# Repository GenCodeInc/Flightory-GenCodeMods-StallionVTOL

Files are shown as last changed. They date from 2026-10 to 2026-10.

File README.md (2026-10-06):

# FlightoryGenCodeMods — Stallion VTOL

Motor-mount modification and wingtip LED scripts for the Flightory Stallion VTOL. All files are in the repository root.

## Motor Mount

Modified front motor mount for the SPARKHOBBY / KINGMAX KM1203MD mini digital servo.

| File | Contents |
| --- | --- |
| `MOTOR MOUNT FRONT-LARGER-HORN-METAL.f3d` | Editable Fusion 360 design |
| `MOTOR MOUNT FRONT-LARGER-HORN-METAL.stl` | Printable mesh |

## Wingtip LED Scripts

Two SpeedyBee WS2812 boards, four LEDs per wing, controlled by a TBS Lucid H7 Wing running ArduPilot Lua through S13. No separate LED controller is used.

### stallion_led_nav.lua

- Left wing red; right wing green.
- All four LEDs on each wing show their navigation colour between flashes.
- Rear two LEDs per wing flash white twice; front two remain red/green.
- Full-brightness navigation colours and white strobes.
- Timing: 60 ms flash, 80 ms gap, 60 ms flash, 900 ms pause.
- Strobes run while disarmed by default.

### stallion_led_demo.lua

Four patterns run for five seconds each, then repeat:

1. **UFO orbit:** purple comet with a fading trail through all eight LEDs in data-chain order.
2. **Police pursuit:** alternating red/blue double flashes between wings.
3. **Rainbow chase:** moving rainbow colours across all eight LEDs.
4. **Reactor pulse:** cyan pulse with a white flash at the peak.

Brightness is controlled by `BRIGHTNESS` (0–255). The demo setting used for this build is `180`.

## LED Wiring

| Source | Destination |
| --- | --- |
| FC S13 | Left-wing DIN |
| Left-wing DOUT | Right-wing DIN, routed through the fuselage |
| Right-wing DOUT | Unconnected |
| Regulated 5 V | Both boards' positive inputs |
| Common ground | Both boards' negative inputs and FC ground |

DIN faces the front of each wing; DOUT faces the rear. The first four pixels are on the left wing, and the next four are on the right wing. The 5 V supply must support the LED load, including white flashes.

## Installation

1. Set `SCR_ENABLE = 1` and `SERVO13_FUNCTION = 94` (Script Out 1).
2. Copy either `stallion_led_nav.lua` or `stallion_led_demo.lua` into `APM/scripts` on the FC's SD card.
3. Remove any other script controlling these LEDs from that folder.
4. Reboot the FC.

Run only one LED script at a time. Filenames may be changed but must retain the `.lua` extension. The demo replaces the navigation-light pattern while installed.

## Credits

Original aircraft design: [Flightory](https://flightory.com/product/stallion/). Modifications: Ed Scott / GenCode. LED project inspired by Ralf Åhman's ESP32 navigation lights.

Original aircraft designs remain subject to the [Flightory License Agreement](https://flightory.com/license/). This repository contains modifications, not the complete aircraft plans.

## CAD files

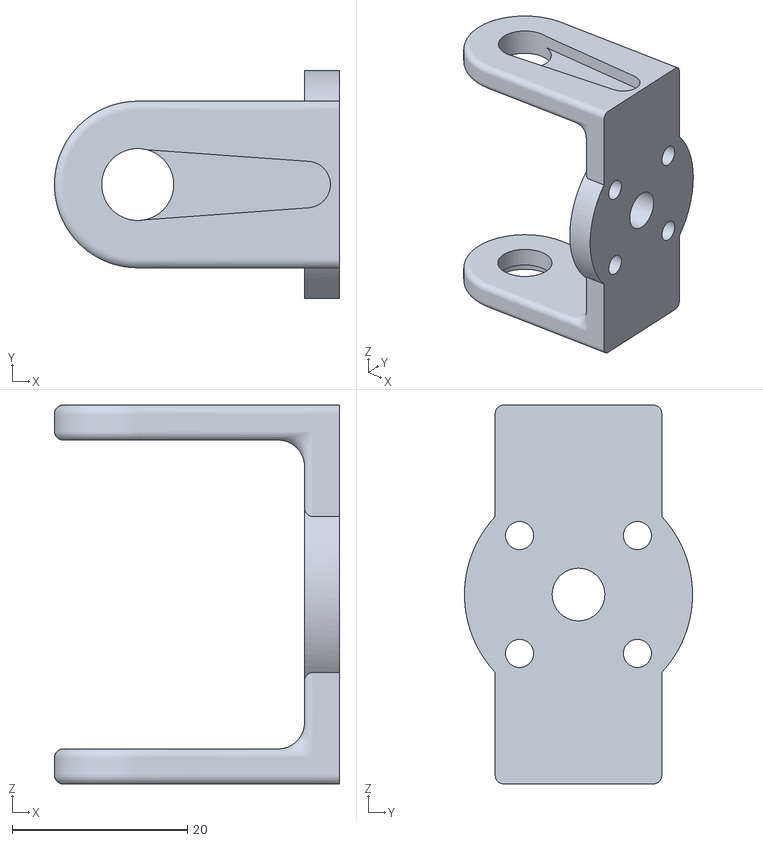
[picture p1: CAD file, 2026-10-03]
MOTOR MOUNT FRONT-LARGER-HORN-METAL.stl
32.5 x 26.0 x 43.2

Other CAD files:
MOTOR MOUNT FRONT-LARGER-HORN-METAL.f3d

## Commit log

2026-10-03 Add Stallion VTOL motor mount modifications
    [MOTOR MOUNT FRONT-LARGER-HORN-METAL.f3d, MOTOR MOUNT FRONT-LARGER-HORN-METAL.stl]
2026-10-06 Add wingtip LED scripts and update README
2026-11-10 v2: add GPS/EKF pre-arm status lights
2026-11-10 Organize printed mods by project
2026-11-10 Document metal-arm motor mount
2026-11-10 Add Stallion GPS holder model
2026-11-10 Add Lucid Wing FC/PDB holder
